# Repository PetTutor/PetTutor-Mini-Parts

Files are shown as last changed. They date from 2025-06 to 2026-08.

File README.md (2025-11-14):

# Pet Tutor Mini: Open-Source Wireless Dog Feeder for Training





## Project Overview

**Pet Tutor Mini** is an open-source, wireless dog feeder designed specifically for **positive reinforcement training**. It dispenses small treats remotely via a mobile app or web interface, helping trainers reward behaviors instantly without interrupting sessions. Built with affordable 3D-printed parts and off-the-shelf electronics, it's customizable, hackable, and perfect for dog owners, trainers, or hobbyists. The original Pet Tutor was created by Smart Animal Training Systems, LLC in 2012 and has gone  through several generations with the new one being the Pet Tutor Mini which is the subject of this open-source project. The Pet Tutor Mini is sold as a completed unit; ;however for hobbiests and developers the parts are provided here at no charge. The Pet Tutor is available for wheelchairs with interfaces for accessibility.

### Key Features
- **Wireless Control**: Bluetooth(50 feet) or Wi-Fi connectivity(internet via MQTT broker) for remote treat dispensing.
- **Modular Design**: Easy-to-print parts.
- **USB-C power plug for Wall or external battery**: A standard USB-C cable and wall plug or external USB style battery provide power.
- **Smart Features**: Auto dispense from browser or app.
- **Open-Source Everything**: Full schematics, code(c++), and files shared under CC BY-SA 4.0 (attribution required; share-alike for derivatives).

> **Note**: While the designs are free to build and modify, commercial versions sold by Smart Animal Training Systems,LLC under the "Pet Tutor" brand include premium support, custom firmware, and quality-tested components—check [Pet Tutor store](https://pettutor.biz) for those.

<!-- remove
# 🐾 PetTutor Mini Parts

Welcome to the **PetTutor Mini Parts** repository! This repo contains 3D printable files, diagrams, and documentation for parts of the **PetTutor Mini** that are available for public use, repair, or customization.

## 📦 What's Included
-->

## This Pet Tutor Mini repository currently includes:

- ✅ STL files for printable components (non-proprietary)
- ✅ Exploded diagrams showing part relationships
- ✅ Licensing information for personal and educational use

> ⚠️ Note: This repository does **not** include any proprietary or internal mechanisms protected under patent or intellectual property rights. Please see the [LICENSE](https://github.com/PetTutor/PetTutor-Mini-Parts/blob/main/LICENSE) section for more info.
<!-- comment out
## 🧩 Available Parts

| Module Name | File Type | Print Notes | Status |
|---|---|---|---|
| [Canister](https://github.com/PetTutor/PetTutor-Mini-Parts/blob/main/Canister/Readme.md) | `.stl` | PLA 0.2mm layer | Public |
| [Tumbler](https://github.com/PetTutor/PetTutor-Mini-Parts/blob/main/Tumbler/Readme.md) | `.stl` | Most PLA 0.2mm layer | Public |
| [PowerBase ESP32](https://github.com/PetTutor/PetTutor-Mini-Parts/blob/main/PowerBase%20ESP32/README.md) | `.stl` | PLA 0.2mm layer | Public |
| [PowerBase Atom](https://github.com/PetTutor/PetTutor-Mini-Parts/tree/main/PowerBase%20Atom/README.md) | `.stl` | PLA 0.2mm layer | Public |
| [Clickers](https://github.com/PetTutor/PetTutor-Mini-Parts/tree/main/Clickers) | `.stl` | PLA 0.2mm layer | Public |

-->
> Need a specific part? Open an issue or submit a request!
> 
# Modules Available   

| Module Name | Description | Contains sw/3D/electronics |
|---|---|:---:|
| [Canister][ca] | Container for food. 1 cup is standard but larger versions are included | 3D |
| [Dispense Mechanism][dm] | This part moves the kibble out of the feeder. It fits into the canister module. The brushes can be printed(TPU) or purchased | 3D |
| [PetTutor Software][sw] | The software is for the PowerBase, Remotes and mobile apps | sw |
| [PowerBase Atom][pba] | The PowerBase contains the stepper motor, Atom and 3D parts | 3D/Elec |
| [PowerBase ESP32][pbe] | Inactive version. No longer in use but provided for information | 3D/Elec |
| [Remotes][rm] | There are two versions of the remote: advanced and basic. The advanced has a larger button for accessibility  | 3D/Elec |

## 🤝 Contributions

We welcome:

- Suggestions for improvements
- Bug reports for fit or functionality
- Requests for additional public-facing parts

Please submit a pull request or open an issue if you’d like to contribute!
## Other resources and contributors to the open Pet Tutor community  
- **[Kona Currents](https://github.com/konacurrents/konacurrents)** :Inventor of the Semantic Marker(r) and developer of advanced firmware for the Pet Tutor

## 📄 License

All parts in this repository are provided under the **Creative Commons Attribution-NonCommercial-ShareAlike 4.0 International (CC BY-NC-SA 4.0)** license.

You are free to:

- Share and adapt the files
- Remix or build upon them

Under the following terms:

- 🏷️ **Attribution** – Give appropriate credit
- 💸 **NonCommercial** – Not for commercial use
- 🔄 **ShareAlike** – Distribute derivatives under the same license

Full license text available [here](https://creativecommons.org/publicdomain/zero/1.0/deed.en).

## 🖨️ 3D Printing Help

If you want to print your own parts and are new to 3D printing follow these simple steps:

STL Files: Download all printable parts from the /stl folder.

Find a friend or local library with 3D printer and ask them to aid in printing.

Recommended Settings:

Layer Height: 0.2 mm

Infill: 15%

Supports: Non unless specified

Other Print Settings: Default

Material: PLA unless otherwise specified

Assembly Tips:

Test-fit parts before gluing or screwing.

Clean up small holes with a drill bit if too tight.

Refer to the exploded diagrams for part orientation.

Need help? Open an issue or start a discussion on this repo.

## 📬 Contact & Support

For technical support or feedback, please contact:

📧 **PetTutor@SmartAnimalTraining.com** 

🌐 [www.pettutor.biz](https://smartanimaltraining.com/)  <-Assembled and tested units available here.

---

Thank you for supporting innovation, repairability, and pet care!

🐶🐱 – *The PetTutor Team*

[ca]: https://github.com/PetTutor/PetTutor-Mini-Parts/tree/main/Canister  
[dm]: https://github.com/PetTutor/PetTutor-Mini-Parts/tree/main/Dispense%20Mechanism
[sw]: https://github.com/PetTutor/PetTutor-Mini-Parts/tree/main/PetTutor%20Software  
[pba]: https://github.com/PetTutor/PetTutor-Mini-Parts/tree/main/PowerBase%20Atom
[pbe]: https://github.com/PetTutor/PetTutor-Mini-Parts/tree/main/PowerBase%20ESP32
[rm]: https://github.com/PetTutor/PetTutor-Mini-Parts/tree/main/Remotes

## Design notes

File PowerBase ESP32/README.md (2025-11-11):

# Older obsolete version of the Pet Tutor PowerBase  
*This version of the PowerBase is no longer made and uses a proprietary electronics board that is no longer made. This obsolete version used an EDP32 single board
processor and a custom interface board.
This is provided for information only.* 

**Click on a part to download:**

- [Base Top](https://github.com/PetTutor/PetTutor-Mini-Parts/blob/main/PowerBase%20ESP32/Base%20top.stl)
- [Center Ring](https://github.com/PetTutor/PetTutor-Mini-Parts/blob/main/PowerBase%20ESP32/Centering%20ring.stl)
- [28BYJ Motor Pin](https://github.com/PetTutor/PetTutor-Mini-Parts/blob/main/PowerBase%20ESP32/28BY-J%20Motor%20Pin.stl)
- [Base V2](https://github.com/PetTutor/PetTutor-Mini-Parts/blob/main/PowerBase%20ESP32/Base%20V2.stl)

All stl files are printed in PLA at .2 Layer Height and 15% infill.

Custom board is purchased through Pettutor.

Other items can be purchased through Amazon.

- [28By-J Motor](https://www.amazon.com/HiLetgo-ULN2003-28BYJ-48-Stepper-4-phase/dp/B00LPK0E5A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)
- [ESP 32](https://www.amazon.com/ESP-WROOM-32-Development-Microcontroller-Integrated-Compatible/dp/B08D5ZD528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)



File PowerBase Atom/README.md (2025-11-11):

- [PowerBase Atom Stepper Motor](https://github.com/PetTutor/PetTutor-Mini-Parts/tree/main/PowerBase%20Atom/PowerBase%20Atom%20Stepper)  This is the current version
- [PowerBase Atom DC Motor](https://github.com/PetTutor/PetTutor-Mini-Parts/tree/main/PowerBase%20Atom/PowerBase%20Atom%20DC%20Motor)

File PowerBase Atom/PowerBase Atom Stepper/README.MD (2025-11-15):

## Assemblies required for a complete Pet Tutor Mini are:  
1. Assembly Power Base Assembly (see parts list below)
2. Subassembly [Canister][ca] This container holds the food and screws onto the Dispense Mechanism to make the Food Assembly.
3. Subassembly [Dispense Mechanism][dm] This is the dispenser mechanism which separates out the kibble and drops it out of the feeder

---  

Base V5 Atom Exploded Assembly
Base V5 Atom Exploded Assembly (2)  

---  

## Bill of Materials Pet Tutor Mini PowerBase Assembly (*est costs in 2025)

| Item # | Part Name/link | Quantity | buy/3D print  | Description / Specs | Source / Supplier | Unit Cost* | Total Cost* |
|:---:|:---|:---:|:---:|:---|:---|---:|---:|
| 1 | [ATOM Lite ESP32 IoT Development Kit][Atom] | 1  | buy  | ATOM ESP32 | M5Stack | $7.50 | $7.50 |
| 2 | [ULN2003 Stepper Motor + ULN2003 Driver Board][db] | 1  | buy  | ELEGOO 28BYJ-48 ULN2003 5V Stepper Motor + ULN2003 Driver Board(5sets $15) | ELEGOO(Amazon) | $3.00 | $3.00 |
| 3 | [Buzzer][buz] | 1  | buy  | Buzzer with wires DC3-12v Active NOTE: must add 2 pin Dupont see [Build Instructions](#Build-Instructions) | bnafes(Amazon) | $0.58 | $0.58 |
| 4 | [Motor mount screws][mms] | 2  | buy  | Phillips Rounded Head Thread-Forming Screws(box 50 $16.46) | McMaster-Carr | $0.33 | $0.66 |
| 5 | [Shoulder screws][scr] | 2  | buy  | Mod-eez 2155 Shoulder Screw 5 mm x 5/8″ (pkg 25 $8.99) | Knapp | $0.36 | $0.72 |
| 6 | [4 pin cable&connectors female 10 cm][4p] | 1  | buy  | Dupont 2.54mm Wire Female to Female Connector & 22AWG Pre-Crimped Cable (motor driver), Single Row 10cm (5pkg $8) | Amazon | $1.60 | $1.60 |
| 7 | [2 pin cable&connectors 30 cm][2p] | 1  | buy  | Dupont 2.54mm Wire Female to Female Connector & 22AWG Pre-Crimped Cable, (motor driver&buzzer) (5 pkg $7.64) | Amazon | $1.53 | $1.53 |
| 8 | [BaseV5 Stepper - 1.stl][s1] | 1  | 3D | Main base for electronics  PLA any color | PLA color choice | n/a | n/a |
| 9 | [BaseV5 Stepper - 2 Clear.stl][cs] | 1  | 3D | Channel for LED light on ATOM clear filament required | ex. [Coex Natural PLA][cn]  | n/a | n/a |
| 10 | [BaseV5 Stepper - 3.stl][s3] | 1  | 3D | Holder for ATOM PLA | PLA color choice | n/a | n/a |
| 11 | [Base top Stepper.stl][ts] | 1  | 3D | Clear top holds motor and transmits led light PLA | ex. [Coex Natural PLA][cn]  | n/a | n/a |
| 12 | [28BY-J Motor Pin.stl][mp] | 1  | 3D | Motor pin fits over motor shaft and drive dispenser | PLA color choice | n/a | n/a |
| 13 | [Centering ring Stepper.stl][crs] | 1  | 3D | Centering ring aligns dispenser | PLA color choice | n/a | n/a |
---

## Build Instructions:  
- All 3D stl files are printed in PLA at .2 Layer Height and 15% infill.
- Cables connect ATOM to stepper motor driver board(2 pin & 4 pin).
- *Add buzzer connector*: 2 wires from buzzer require adding Dupont 2-pin connector. [Kit with tool and connector][tool]
- The motor pin is glued(ex. silicon glue) on the motor shaft. Note: height is critical along the shaft so mount motor and use the dispense canister assembly to push the pin down on shaft with glue
- Advanced firmware option: This has capabilites to allow the Pet Tutor Mini to connect to both WiFi and Bluetooth. It also can run other addons via the Groove connector.
- In addition to the feeder electronics module the dispenser is required and attached to the module. The food assembly is built from: [Canister][ca] and [Dispense Mechanism][dm] The Dispense Mechanism subassembly fits inside the Canister subassembly and this food assembly twists onto the PowerBase assembly.
- Basic firmware option:  This allows the feeder to be controlled from bluetooth.

---

*Last updated: November 14, 2025*

<!-- The links below will not show up in the render but are used as shortcuts in the code -->
[Atom]: https://shop.m5stack.com/products/atom-lite-esp32-development-kit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
[buz]: https://www.amazon.com/QMseller-Connector-Active-Plastic-Electronic/dp/B07VX87W5Q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
[scr]: https://knappconnectors.com/mod-eez-system/shoulder-screws/mod-eez-2155-shoulder-screw-5mm-x-5-8-inch/
[4p]: https://www.amazon.com/gp/aw/d/B0CCV3NJ8Q/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
[2p]: https://www.amazon.com/gp/aw/d/B0CCV3PXFP/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
[s1]: https://github.com/PetTutor/PetTutor-Mini-Parts/blob/main/PowerBase%20Atom/PowerBase%20Atom%20Stepper/BaseV5%20Stepper%20-%201.stl
[db]: https://www.amazon.com/ELEGOO-28BYJ-48-ULN2003-Stepper-Arduino/dp/B01CP18J4A
[mms]: https://www.mcmaster.com/catalog/131/3432/99461A505
[cs]: https://github.com/PetTutor/PetTutor-Mini-Parts/blob/main/PowerBase%20Atom/PowerBase%20Atom%20Stepper/BaseV5%20Stepper%20-%202%20Clear.stl
[s3]: https://github.com/PetTutor/PetTutor-Mini-Parts/blob/main/PowerBase%20Atom/PowerBase%20Atom%20Stepper/BaseV5%20Stepper%20-%203.stl
[ts]: https://github.com/PetTutor/PetTutor-Mini-Parts/blob/main/PowerBase%20Atom/PowerBase%20Atom%20Stepper/Base%20top%20Stepper.stl
[mp]: https://github.com/PetTutor/PetTutor-Mini-Parts/blob/main/PowerBase%20Atom/PowerBase%20Atom%20Stepper/28BY-J%20Motor%20Pin.stl
[crs]: https://github.com/PetTutor/PetTutor-Mini-Parts/blob/main/PowerBase%20Atom/PowerBase%20Atom%20Stepper/Centering%20ring%20Stepper.stl
[dm]: https://github.com/PetTutor/PetTutor-Mini-Parts/tree/main/Dispense%20Mechanism
[cn]: https://coex3d.com/products/natural-pla-175mm-1kg
[tool]: https://www.amazon.com/Taiss-Ratcheting-Connector-Crimping-Terminal/dp/B0B11RLGDZ?th=1
[ca]: https://github.com/PetTutor/PetTutor-Mini-Parts/tree/main/Canister

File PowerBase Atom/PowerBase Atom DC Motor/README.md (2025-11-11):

# Two versions of the PowerBase: Stepper motor(recommended) and DC Motor(not recommended)

During development a version of the PowerBase using a *DC motor* was developed and tested. That is the version listed below.  However, during testing
we found the noise from motor scared some dogs. While this version had superior torque the noise was too great. So the new version using the *stepper motor* was decveloped and is now in production. This is provided for anyone that would like to experiement with a different version.

**Click on a part to download:**

- [Base Top v5](https://github.com/PetTutor/PetTutor-Mini-Parts/blob/main/PowerBase%20Atom/Base%20top%20V5.stl)
- [BaseV5 - 1](https://github.com/PetTutor/PetTutor-Mini-Parts/blob/main/PowerBase%20Atom/BaseV5%20-%201.stl)
- [BaseV5 - 2](https://github.com/PetTutor/PetTutor-Mini-Parts/blob/main/PowerBase%20Atom/BaseV5%20-%202%20Clear.stl)
- [BaseV5 - 3](https://github.com/PetTutor/PetTutor-Mini-Parts/blob/main/PowerBase%20Atom/BaseV5%20-%203.stl)
- [Centering Ring V5](https://github.com/PetTutor/PetTutor-Mini-Parts/blob/main/PowerBase%20Atom/Centering%20ring%20V5.stl)
- [N20 Motor Pin](https://github.com/PetTutor/PetTutor-Mini-Parts/blob/main/PowerBase%20Atom/N20%20Motor%20Pin.stl)

All stl files are printed in PLA at .2 Layer Height and 15% infill. 

Other items can be purchased through Amazon or other vendors.

- [Atom](https://shop.m5stack.com/products/atom-lite-esp32-development-kit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)
- [N20 Motor](https://www.amazon.com/DIANN-10pcs-Micro-Motor-Gearbox/dp/B0CRKXXGXC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)
- [L9110 Motor Driver](https://www.amazon.com/HiLetgo-H-bridge-Stepper-Controller-Arduino/dp/B00M0F243E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)
- [Buzzer](https://www.amazon.com/QMseller-Connector-Active-Plastic-Electronic/dp/B07VX87W5Q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)




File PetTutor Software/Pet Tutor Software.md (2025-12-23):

# Software packages for Pet Tutor  
- **Feeder:** The firmware in the feeder allows it to wirelessly connect to BLE(Bluetooth Low Energy) devices like a phone or one of the Pet Tutor remotes. The feeder can also simultaneously connect to WiFi to provide control over the internet from a browser. The internet option uses a MQTT IOT broker to manage status and control to the feeder.
- **Remote:** This firmware allows the remote to find and connect to the feeder using BLE. The button on the remote sends the feed command to the feeder over BLE.
- **Phones:** The apps for Android and iOS provide the phone with the ability to connect to the feeder via BLE and send commands.  In addition the user can use a browser on the phone to send feed commands over the internet from the phone. Using the phone browser does NOT require an app and just uses the browser.
- **Summary:** The feeder can be controlled via BLE or WiFI or both at the same time. The remotes or phones can be used for BLE connection which is easy to setup but has shorter range. For longer range the WiFi option is a good choice. When using WiFi the feeder is setup with credentials for the local WiFi router(SSID/Password) and user cloud account(ID/Password). Customers who buy the Pet Tutor Mini will get a free cloud account but DIY builders will need to provide their own cloud MQTT broker. Basic functions firmware for the feeder and remote can be downloaded and compiled on the Arduino IDE.

---  
# Firmware for devices and apps for the phone  

| Device | Software download link | binary/source | Description | Software Contributor  | Comment |
|:---:|:---|:---:|:---:|:---:|:---|
| Android | [Android APK][apk] | binary| Not in app store. download and manually install  | Pet Tutor (Orion Patrie) | | 
| iOS | [Apple iOS][ios] | binary| In Apple Store for fee | Kona Currents,LLC (Scott Moody) | Several advanced features to monitor MQTT traffic, Semantic Marker developer |  
| Feeder | [Arduino ino][ino] | source | Arduino source code (c++) | Pet Tutor (Orion Patrie) | Basic firmware |  
| Feeder | [Advanced firmware][kc] | source | Arduino source code (c++) | [Kona Currents,LLC (Scott Moody)][kc] | Advanced firmware |  
| Basic Remote  | [Basic Remote][frmRemote]  | source | Basic remote Arduino C++  | Pet Tutor (Orion Patrie)  | |  

---

*Updated 11 NOV 2025*

---
[apk]: https://drive.google.com/file/d/19x49JGUla84gN7AuETKdELnhjsQVB5Vx/view?usp=sharing
[frm]: https://github.com/PetTutor/PetTutor-Mini-Parts/blob/main/PetTutor%20Basic%20Software/PTMini_Basic.ino
[ios]: https://apps.apple.com/us/app/semanticmarker/id6443887496  
[ino]: https://github.com/PetTutor/PetTutor-Mini-Parts/blob/main/PetTutor%20Software/PTMini_Basic.ino
[kc]: https://github.com/konacurrents/konacurrents
[frmRemote]: https://github.com/PetTutor/PetTutor-Mini-Parts/blob/main/PetTutor%20Software/PTClicker.ino

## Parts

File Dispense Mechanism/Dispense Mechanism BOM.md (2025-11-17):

# Exploded view of Dispense Mechanism (with PowerBase Assembly)  

BTum Parts

---

## Bill of Materials: Dispense Mechanism

| Item # | Part Name/link | Quantity | buy/3D print  | Description / Specs | Source / Supplier | Unit Cost* | Total Cost* |
|:---:|:---|:---:|:---:|:---|:---|---:|---:|
| 1 | [BTum - 1][bt1] | 1  | 3D | BTum 1.STL (PLA) | PLA color choice | na | na |
| 2 | [BTum - 2][bt2] | 1  | 3D | BTum 2.STL (PLA) | PLA color choice | na | na |
| 3 | [BTum - 3][bt3] | 1  | 3D | BTum 3.STL (PLA) | PLA color choice | na | na |
| 4 | [BTum - 4][bt4] | 1  | 3D | BTum 4.STL (TPU) | PLA color choice | na | na |
| 5 | [BTum - ST Adapter][bta] | 1  | 3D | BTum - ST Adapter.STL (PLA) optional Small Treat Adapter | PLA color choice | na | na |
| 6 | Brush waffer | 10 | 3D/buy  | 10 brush wafers can be printed in TPU [BTum 5.STL][bt5] or buy silicone type with better long term performance | [TPU][bta] or [silicone][si] | $4.00 silicone | $40.00 [silicone set][si] |

---

## Build Instructions:  
- All 3D stl files are printed in PLA at .2 Layer Height and 15% infill
- BTum 4 is printed out of TPU at .2 layer height and 15% infill
- Silicon brushes are not printed and need to be purchased from PetTutor or you can download and print BTum - 5 out of TPU.  The TPU version do not last as long as the silicon brushes and will need to be changed often.
---

*Last updated: November 10, 2025*  

[bt1]: https://github.com/PetTutor/PetTutor-Mini-Parts/blob/main/Dispense%20Mechanism/BTum%20%20-%201.stl  
[bt2]: https://github.com/PetTutor/PetTutor-Mini-Parts/blob/main/Dispense%20Mechanism/BTum%20-%202.stl
[bt3]: https://github.com/PetTutor/PetTutor-Mini-Parts/blob/main/Dispense%20Mechanism/BTum%20-%203.stl
[bt4]: https://github.com/PetTutor/PetTutor-Mini-Parts/blob/main/Dispense%20Mechanism/BTum%20-%204%20TPU.stl  
[bt5]: https://github.com/PetTutor/PetTutor-Mini-Parts/blob/main/Dispense%20Mechanism/BTum%20-%205%20TPU.stl  
[bta]: https://github.com/PetTutor/PetTutor-Mini-Parts/blob/main/Dispense%20Mechanism/BTum%20-%20ST%20Adapter.stl  
[si]: https://smartanimaltraining.com/products/brush-waffer-silicone-set

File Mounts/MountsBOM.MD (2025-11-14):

# The feeder has 2 holes in the bottom that allow it to attach to accessory mounts.  

## Mounts  
- Floor base bowl. This can be set on the floor or attached to a wheelchair mount  
- Wheelchair mounts

<!--  comment out
# Mounts  

| Item # | Part Name/link | Quantity | buy/3D print  | Description / Specs | Source / Supplier | Unit Cost* | Total Cost* |
|:---:|:---|:---:|:---:|:---|:---|---:|---:|
| 1 | [Floor mount.stl][fm] | 1  | 3D | 1 Cup Canister.stl (PLA) | PLA color choice | na | na |
| 2 | [1.5 Cup Canister.stl][c2] | 1  | 3D | 1.5 Cup Canister.stl (PLA) | PLA color choice | na | na |
| 3 | [2 Cup Canister.stl][c3] | 1  | 3D | 2 Cup Canister.stl (PLA) | PLA color choice | na | na |
| 4 | [Can x4 - 4 Cup Canister.stl][c4] | 1  | 3D | Can x4 - 4 Cup Canister.stl | PLA color choice | na | na |
| 5 | [Lid.stl][ld] | 1  | 3D | Lid (PLA) | PLA color choice | na | na |

comment out -->
---

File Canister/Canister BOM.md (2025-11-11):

# Canister Exploded View and BOM



---
# Canister BOM  

| Item # | Part Name/link | Quantity | buy/3D print  | Description / Specs | Source / Supplier | Unit Cost* | Total Cost* |
|:---:|:---|:---:|:---:|:---|:---|---:|---:|
| 1 | [1 Cup Canister.stl][c1] | 1  | 3D | 1 Cup Canister.stl (PLA) | PLA color choice | na | na |
| 2 | [1.5 Cup Canister.stl][c2] | 1  | 3D | 1.5 Cup Canister.stl (PLA) | PLA color choice | na | na |
| 3 | [2 Cup Canister.stl][c3] | 1  | 3D | 2 Cup Canister.stl (PLA) | PLA color choice | na | na |
| 4 | [Can x4 - 4 Cup Canister.stl][c4] | 1  | 3D | Can x4 - 4 Cup Canister.stl | PLA color choice | na | na |
| 5 | [Lid.stl][ld] | 1  | 3D | Lid (PLA) | PLA color choice | na | na |

---
All STL files should be properly aligned for support-free
printing. Note some slicers may complain about floating cantilevers on
the "cup" objects, however this can safely be ignored.

Suggested print settings include

* Matte or "Basic" PLA
* 0.4mm nozzle, with 0.2mm layer height
* 15% "grid" infill, 2 walls, 3 top / bottom layers

[c1]: https://github.com/PetTutor/PetTutor-Mini-Parts/blob/main/Canister/1%20%20Cup%20Canister.stl  
[c2]: https://github.com/PetTutor/PetTutor-Mini-Parts/blob/main/Canister/1.5%20Cup%20Canister.stl  
[c3]: https://github.com/PetTutor/PetTutor-Mini-Parts/blob/main/Canister/2%20Cup%20Canister.stl  
[c4]: https://github.com/PetTutor/PetTutor-Mini-Parts/blob/main/Canister/Can%20x4%20-%204%20Cup%20Canister.stl  
[ld]: https://github.com/PetTutor/PetTutor-Mini-Parts/blob/main/Canister/Lid.stl

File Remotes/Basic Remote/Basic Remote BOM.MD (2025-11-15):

## Pet Tutor Mini:  Basic Remote  
This remote provides a basic function of connecting to the feeder and provide a simple button to trigger the feeder.  

---
Clicker  

---

## Bill of Materials: Basic Remote

| Item # | Part Name/link | Quantity | buy/3D print  | Description / Specs | Source / Supplier | Unit Cost* | Total Cost* |
|:---:|:---|:---:|:---:|:---|:---|---:|---:|
| 1 | [ATOM Lite ESP32 IoT Development Kit][Atom] | 1  | buy | ATOM ESP32 | M5Stack | $7.50 | $7.50 |
| 2 | [ATOM Battery Accessory][tb] | 1  | buy | EATOM TailBat - Battery Accessory for ATOM is rechargeable | M5Stack | $9.50 | $9.50 |
| 3 | [Top Case.stl][tc] | 1  | 3D  | Top Case | PLA color choice | na | na |
| 4 | [Bottom Case.stl][bc] | 1  | 3D  | Bottom Case | PLA color choice | na | na |
| 5 | [Button.STL][bt] | 1  | 3D  | Button | PLA color choice | na | na |
| 6 | [Grip][gp] | 1  | 3D  |PTMini Clicker - Grip (TPU).stl | TPU | na | na |  

---  

## Build Instructions  

- All stl files are printed in PLA (Unless otherwise stated) at .2 Layer Height and 15% infill.

[Atom]: https://shop.m5stack.com/products/atom-lite-esp32-development-kit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  
[tb]: https://shop.m5stack.com/products/atom-tailbat  
[tc]: https://github.com/PetTutor/PetTutor-Mini-Parts/blob/main/Remotes/Basic%20Remote/PTMini%20Clicker%20-%20Top%20Case%20(PLA).stl  
[bc]: https://github.com/PetTutor/PetTutor-Mini-Parts/blob/main/Remotes/Basic%20Remote/PTMini%20Clicker%20-%20Bottom%20Case%20(PLA).stl  
[bt]: https://github.com/PetTutor/PetTutor-Mini-Parts/blob/main/Remotes/Basic%20Remote/PTMini%20Clicker%20-%20Button%20(Clear%20PLA).stl  
[gp]: https://github.com/PetTutor/PetTutor-Mini-Parts/blob/main/Remotes/Basic%20Remote/PTMini%20Clicker%20-%20Grip%20(TPU).stl

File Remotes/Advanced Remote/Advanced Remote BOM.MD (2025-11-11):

---  

## Pet Tutor Mini Advanced Remote  
This remote provides additions capabilities compared to the Basic Remote. Among other things the Advanced Remote has a big button which   
is useful for those with limited hand mobility. This unit also offers more options to attach other accessories.  

---
Smart Clicker (1)
---  

## Bill of Materials: Advanced Remote

| Item # | Part Name/link | Quantity | buy/3D print  | Description / Specs | Source / Supplier | Unit Cost* | Total Cost* |
|:---:|:---|:---:|:---:|:---|:---|---:|---:|
| 1 | [ATOM Lite ESP32 IoT Development Kit][Atom] | 1  | buy | ATOM ESP32 | M5Stack | $7.50 | $7.50 |
| 2 | [ATOM Battery Accessory][tb] | 1  | buy | EATOM TailBat - Battery Accessory for ATOM is rechargeable | M5Stack | $9.50 | $9.50 |
| 3 | [Button & cable][bt] | 1  | buy | Mechanical Key Button Unit includes HY2.0-4P Cable (20cm) | M5Stack | $3.95 | $3.95 |
| 4 | [Atom Extension][ae] | 1  | buy | ATOMIC PortABC Extension Base | M5Stack | $3.50 | $3.50 |
| 5 | [Handle Top.stl][ht] | 1  | 3D  | Top Handle | PLA color choice | na | na |
| 6 | [Handle Bottom.stl][hb] | 1  | 3D  | Handle Bottom | PLA color choice | na | na |

---

## Build Instructions:  
- All 3D stl files are printed in PLA at .2 Layer Height and 15% infill
- Firmware can be downloaded to operation the Advanced Remote and connect via Bluetooth Low Energy to the feeder.  

---

*Last updated: November 10, 2025*  

[Atom]: https://shop.m5stack.com/products/atom-lite-esp32-development-kit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  
[tb]: https://shop.m5stack.com/products/atom-tailbat  
[bt]: https://shop.m5stack.com/products/mechanical-key-button-unit 
[ae]: https://shop.m5stack.com/products/atomic-portabc-extension-base
[ht]: https://github.com/PetTutor/PetTutor-Mini-Parts/blob/main/Clickers/Smart%20Clicker/Handle%20Top.stl  
[hb]: https://github.com/PetTutor/PetTutor-Mini-Parts/blob/main/Clickers/Smart%20Clicker/Handle%20Bottom.stl

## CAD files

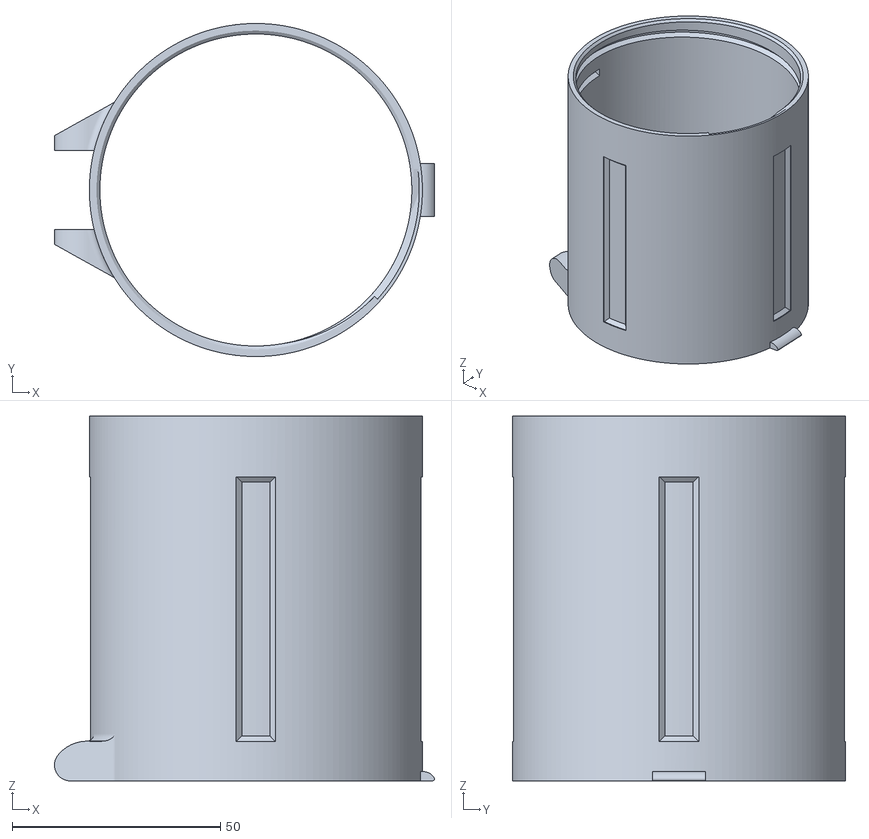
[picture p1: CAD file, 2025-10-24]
Canister/1 Cup Canister.stl
91.3 x 80.0 x 87.6

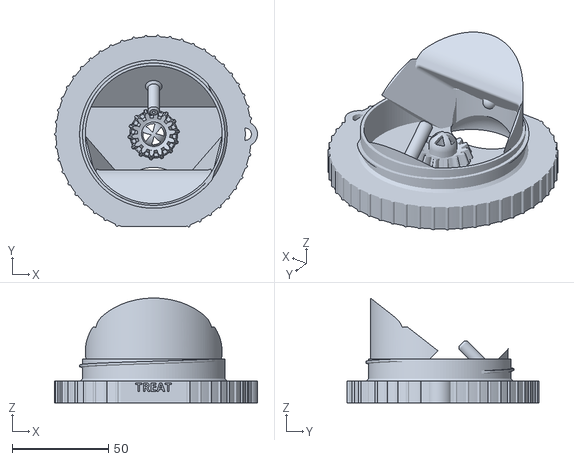
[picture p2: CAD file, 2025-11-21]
Dispense Mechanism/BTum - 1.stl
105.6 x 99.8 x 54.6

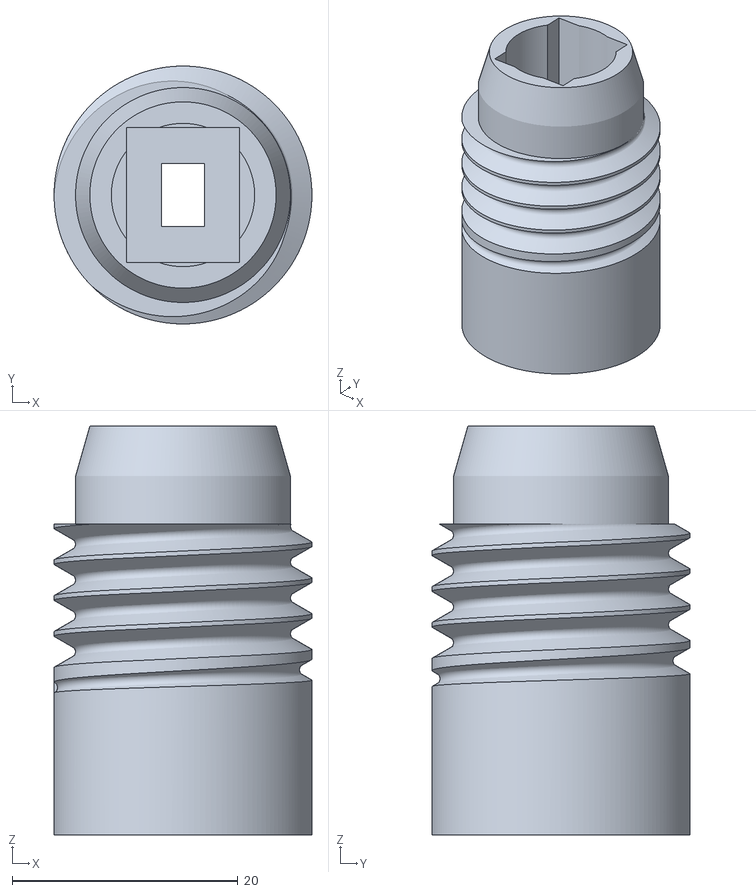
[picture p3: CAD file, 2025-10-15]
PowerBase Atom/PowerBase Atom DC Motor/Centering ring V5.stl
22.9 x 22.9 x 36.3

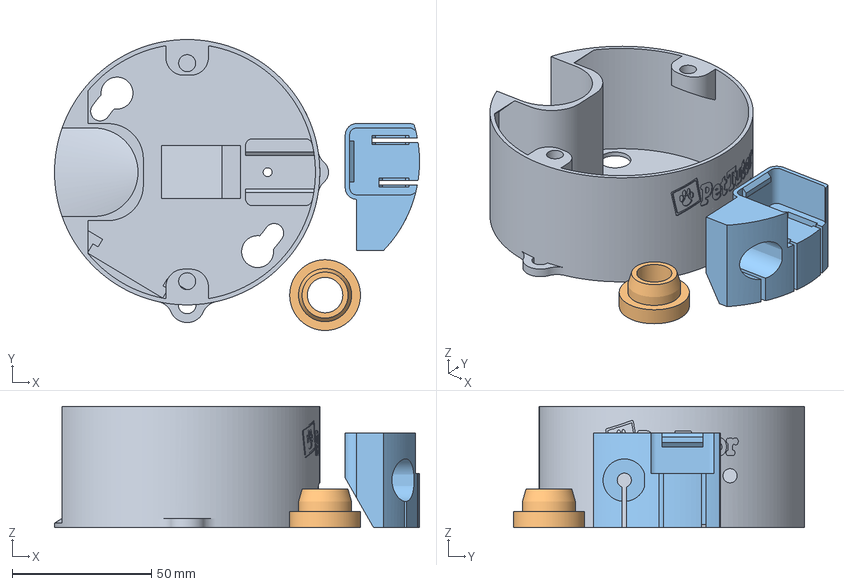
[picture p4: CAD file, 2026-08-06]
PowerBase Atom/PowerBase Atom Stepper/PowerBase Color Parts.3mf
131.0 x 104.4 x 43.5 mm
BaseV5 Stepper - 1.stl
Centering ring Stepper.stl
BaseV5 Stepper - 3.stl

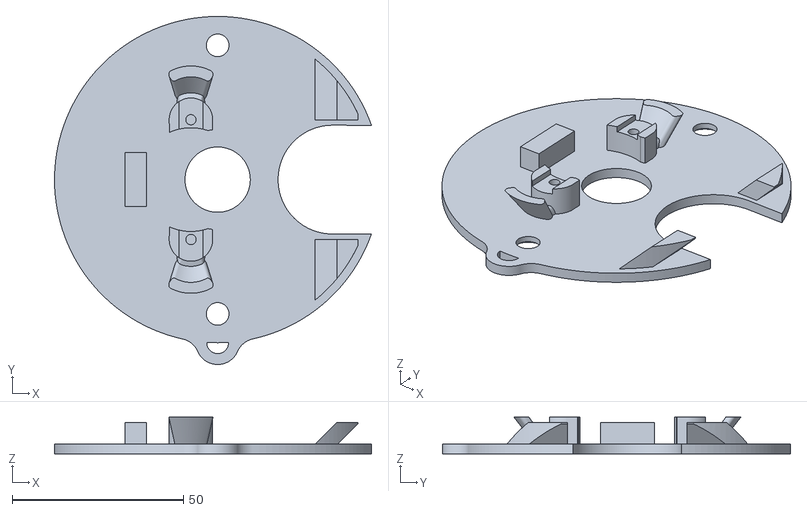
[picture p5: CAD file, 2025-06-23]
PowerBase ESP32/Base top.stl
92.5 x 101.6 x 10.8

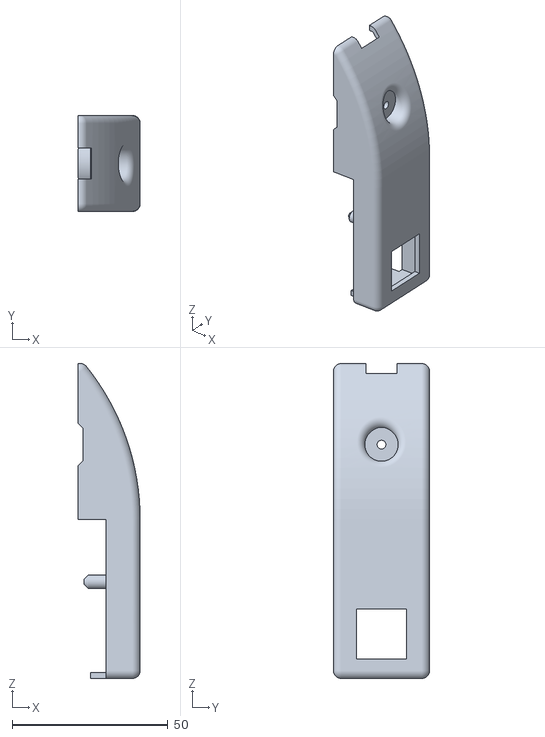
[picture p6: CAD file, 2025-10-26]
Remotes/Advanced Remote/Handle Bottom.stl
20.0 x 30.9 x 101.0

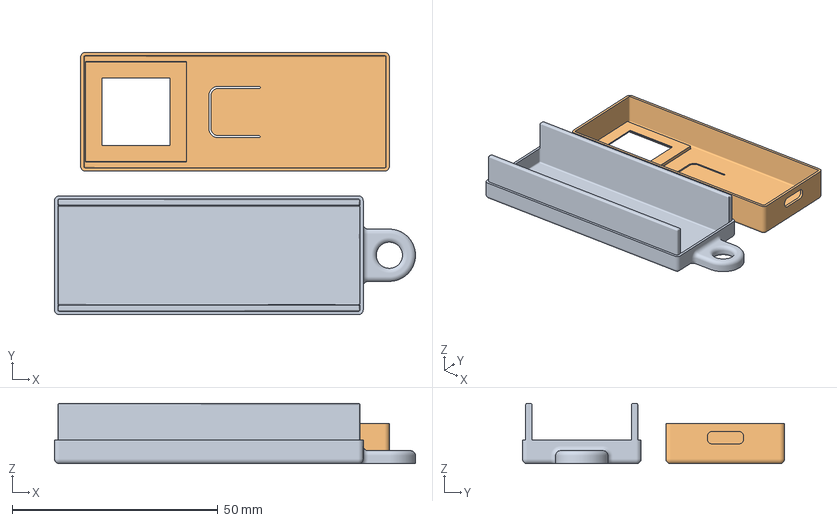
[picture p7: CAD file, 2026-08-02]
Remotes/Basic Remote/Remote Case.3mf
87.8 x 63.8 x 14.7 mm
Basic Remote - Bottom Case (PLA).stl
Basic Remote S3 - Top Case (PLA).stl

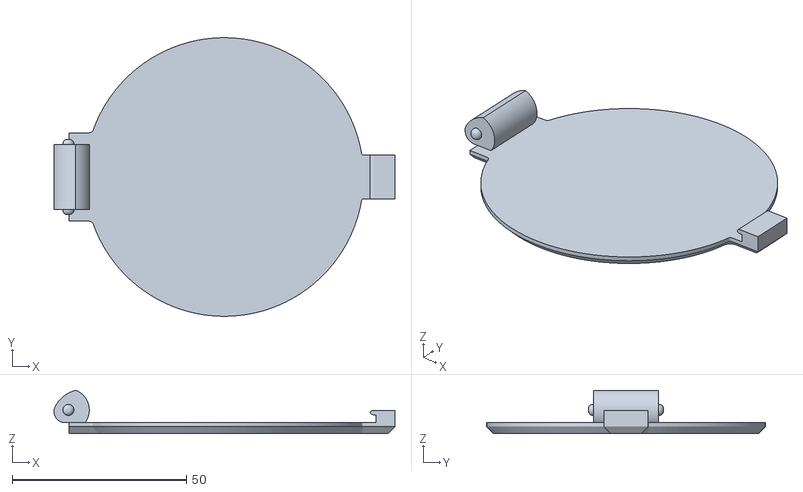
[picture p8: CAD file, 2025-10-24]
Canister/Lid.stl
97.9 x 80.0 x 12.5

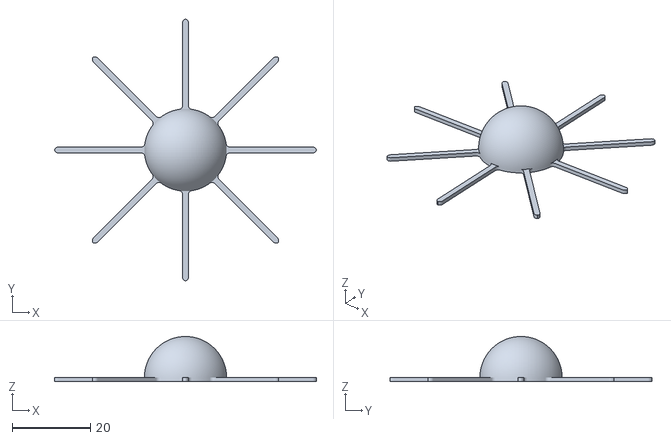
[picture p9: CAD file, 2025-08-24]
Dispense Mechanism/BTum - 4 TPU.stl
66.9 x 66.9 x 11.5

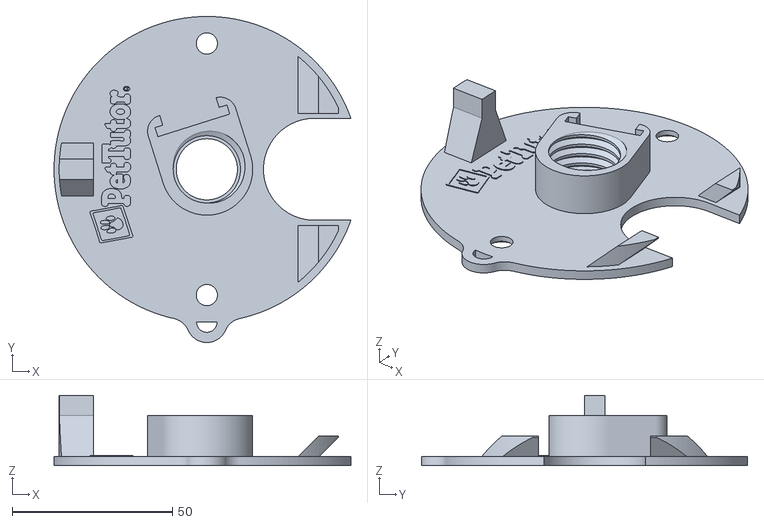
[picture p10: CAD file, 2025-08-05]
PowerBase Atom/PowerBase Atom DC Motor/Base top V5.stl
92.5 x 101.6 x 21.9

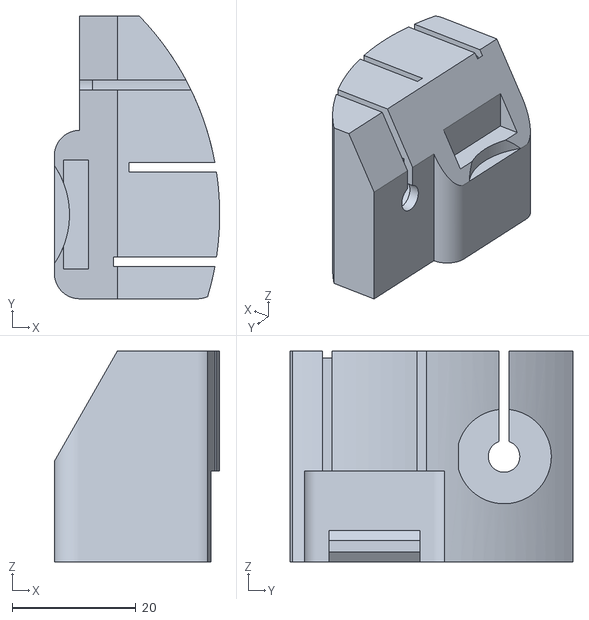
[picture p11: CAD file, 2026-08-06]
PowerBase Atom/PowerBase Atom Stepper/BaseV5 Stepper - 3.stl
26.7 x 45.6 x 34.0

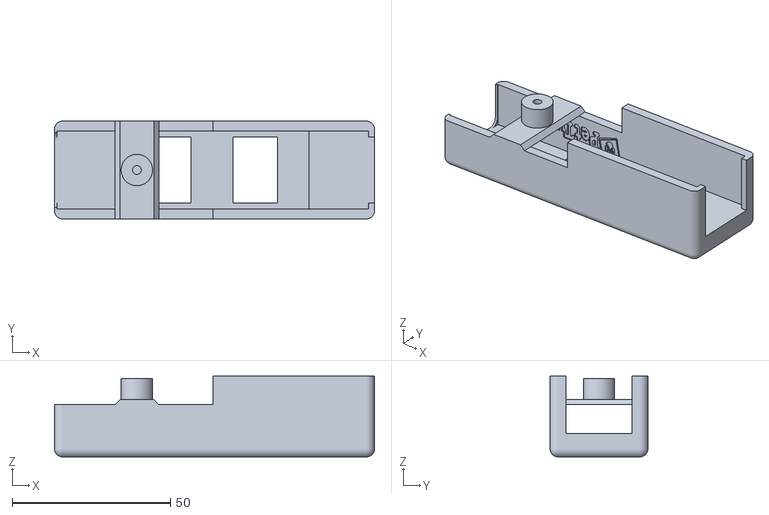
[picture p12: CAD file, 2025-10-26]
Remotes/Advanced Remote/Handle Top.stl
101.0 x 30.9 x 25.5

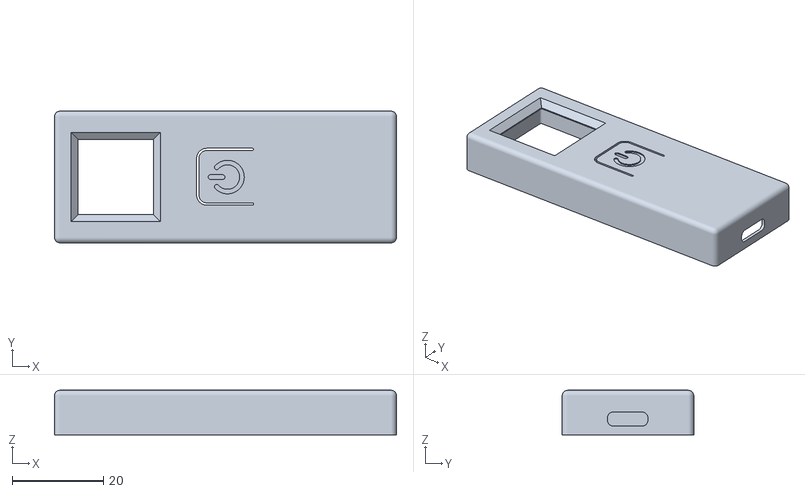
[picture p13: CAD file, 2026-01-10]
Remotes/Basic Remote/Basic Remote S3 - Top Case (PLA).stl
75.1 x 28.9 x 9.77

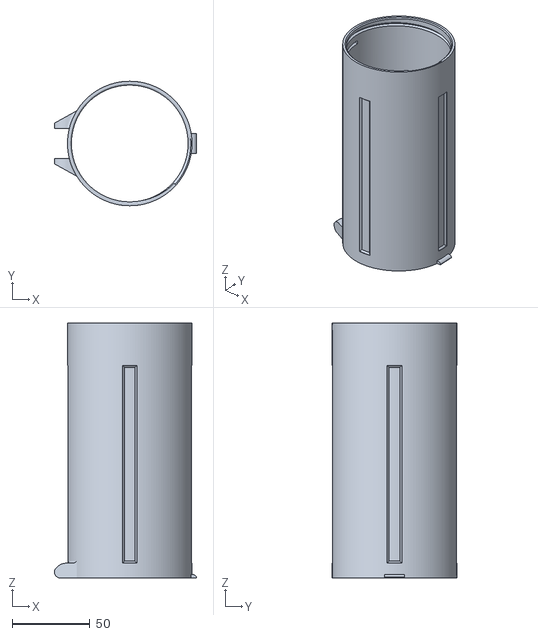
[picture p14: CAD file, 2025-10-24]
Canister/2 Cup Canister.stl
91.3 x 80.0 x 163.8

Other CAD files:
Dispense Mechanism/BTum - 3.stl
PowerBase Atom/PowerBase Atom DC Motor/BaseV5 - 3.stl
PowerBase Atom/PowerBase Atom Stepper/BaseV5 Stepper - 2 Clear.stl
Remotes/Basic Remote/Basic Remote - Top Case (PLA).stl
Canister/1.5 Cup Canister.stl
Canister/Can x4 - 4 Cup Canister.stl
Dispense Mechanism/BTum - 2.stl
Dispense Mechanism/BTum - 5 TPU.stl
Dispense Mechanism/BTum - ST Adapter.stl
PowerBase Atom/PowerBase Atom DC Motor/BaseV5 - 1.stl
PowerBase Atom/PowerBase Atom DC Motor/BaseV5 - 2 Clear.stl
PowerBase Atom/PowerBase Atom DC Motor/N20 Motor Pin.stl
PowerBase Atom/PowerBase Atom Stepper/28BY-J Motor Pin.stl
PowerBase Atom/PowerBase Atom Stepper/Base top Stepper.stl
PowerBase Atom/PowerBase Atom Stepper/BaseV5 Stepper - 1.stl
PowerBase Atom/PowerBase Atom Stepper/Centering ring Stepper.stl
Remotes/Basic Remote/Basic Remote - Bottom Case (PLA).stl
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

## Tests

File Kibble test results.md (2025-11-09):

# Results of testing kibble in Pet Tutor Mini

**Open in Google Docs (editable)** → [Kibble test results](https://docs.google.com/spreadsheets/d/1Jjmwx9EtroDBZK3UN8GiRwEKW_PLVF-9acC-SBAR-ZY/edit?gid=0#gid=0)

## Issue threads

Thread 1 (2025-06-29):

Wiring Diagram for M5Atom version

konacurrents, 2025-06-29:
The parts list and 3d printed parts are awesome.
Next people need to know is the wiring diagram for hooking up the motor and buzzer.

Here is one that Orion made in rough draft, but useful.

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

# M5 Atom Wiring
The diagram above corresponds to the following of the M5Atom.

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

# Bootstrap program for getting the M5Atom software

- [ ] use this bootstrap program
[M5Atom Bootstrap Program](https://github.com/konacurrents/ESP_M5_BOOTSTRAP/tree/main
)

opatrie, 2025-07-01:
README.md was updated with wiring diagram.

https://github.com/PetTutor/PetTutor-Mini-Parts/blob/main/PowerBase%20Atom/README.md

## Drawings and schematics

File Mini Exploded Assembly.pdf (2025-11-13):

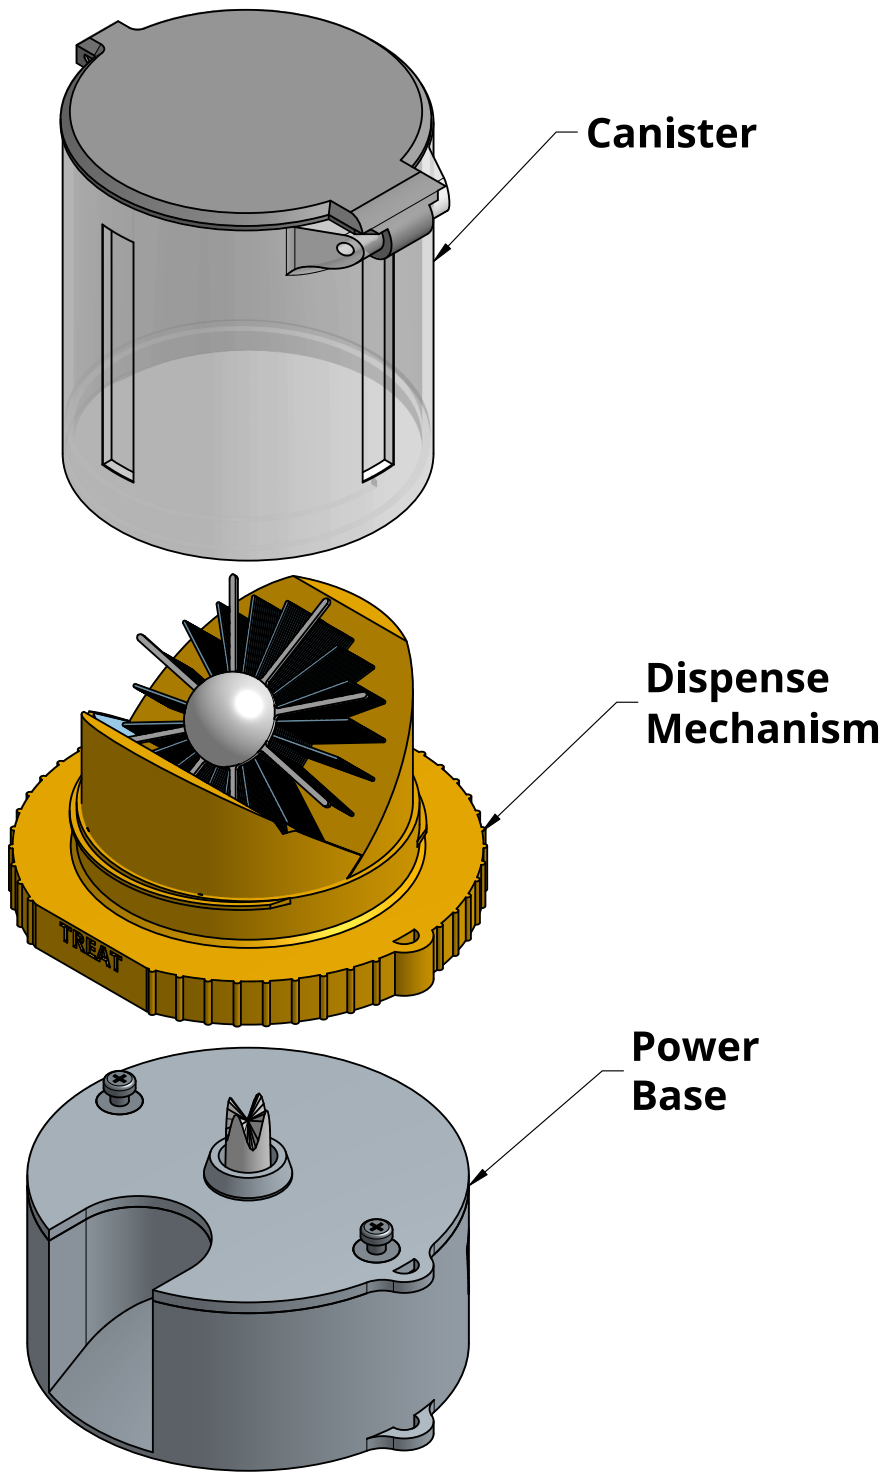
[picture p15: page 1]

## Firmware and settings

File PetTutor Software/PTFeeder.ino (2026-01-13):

#include <M5Atom.h>
#include <BLEDevice.h>
#include <BLEUtils.h>
#include <BLEServer.h>
#include <AccelStepper.h>

// ================= PINS =================
#define MOTOR_PIN1 22
#define MOTOR_PIN2 19
#define MOTOR_PIN3 23
#define MOTOR_PIN4 33

#define BUZZER1 21   // G21 HIGH
#define BUZZER2 25   // G25 LOW

// ================= STEPPER =================
AccelStepper stepper(AccelStepper::FULL4WIRE,
                     MOTOR_PIN1, MOTOR_PIN3,
                     MOTOR_PIN2, MOTOR_PIN4);

int stepsPerFeed = 200;
bool motorDirection = true;
bool motorRunning = false;
unsigned long motorStartTime = 0;

// ================= BUZZER =================
bool buzzerEnabled = false;   // controlled by B / b

// ================= BLE =================
#define SERVICE_UUID        "B0E6A4BF-CCCC-FFFF-330C-0000000000F0"
#define CHARACTERISTIC_UUID "B0E6A4BF-CCCC-FFFF-330C-0000000000F1"

BLEServer* pServer = nullptr;
BLECharacteristic* pCharacteristic = nullptr;

// ================= BLE CALLBACK =================
class MyCallbacks : public BLECharacteristicCallbacks {
  void onWrite(BLECharacteristic* characteristic) override {
    std::string value = characteristic->getValue();
    if (value.length() == 0) return;

    String rxValue = String(value.c_str());
    Serial.print("Received: ");
    Serial.println(rxValue);

    // ---- FEED ----
    if (rxValue == "s") {
      motorRunning = true;
      motorStartTime = millis();

      stepper.setMaxSpeed(600);
      stepper.setAcceleration(300);
      stepper.moveTo(motorDirection ? stepsPerFeed : -stepsPerFeed);
      motorDirection = !motorDirection;

      M5.dis.drawpix(0, 0xFF0000); // red during feed
    }

    // ---- BUZZER ENABLE ----
    else if (rxValue == "B") {
      buzzerEnabled = true;
      Serial.println("Buzzer enabled");
    }

    // ---- BUZZER DISABLE ----
    else if (rxValue == "b") {
      buzzerEnabled = false;
      digitalWrite(BUZZER1, LOW);
      digitalWrite(BUZZER2, LOW);
      Serial.println("Buzzer disabled");
    }

    // ---- CHANGE STEPS ----
    else {
      int newSteps = rxValue.toInt();
      if (newSteps > 0 && newSteps < 20000) {
        stepsPerFeed = newSteps;
        Serial.print("Steps per feed set to ");
        Serial.println(stepsPerFeed);
      }
    }
  }
};

void setup() {
  Serial.begin(115200);
  M5.begin(true, false, true);

  pinMode(BUZZER1, OUTPUT);
  pinMode(BUZZER2, OUTPUT);
  digitalWrite(BUZZER1, LOW);
  digitalWrite(BUZZER2, LOW);

  stepper.setMaxSpeed(600);
  stepper.setAcceleration(300);

  // BLE setup
  BLEDevice::init("PTFeeder");
  pServer = BLEDevice::createServer();
  BLEService* service = pServer->createService(SERVICE_UUID);

  pCharacteristic = service->createCharacteristic(
    CHARACTERISTIC_UUID,
    BLECharacteristic::PROPERTY_WRITE
  );

  pCharacteristic->setCallbacks(new MyCallbacks());
  service->start();

  BLEAdvertising* advertising = BLEDevice::getAdvertising();
  advertising->addServiceUUID(SERVICE_UUID);
  advertising->start();

  M5.dis.drawpix(0, 0xFFFFFF); // white = idle
  Serial.println("PTFeeder BLE ready");
}

void loop() {
  M5.update();

  // ---- MOTOR RUN ----
  if (motorRunning) {
    if (stepper.distanceToGo() != 0) {
      stepper.run();

      // ---- BUZZER DURING FEED ----
      if (buzzerEnabled && millis() - motorStartTime < 5000) {
        digitalWrite(BUZZER1, HIGH); // G21 HIGH
        digitalWrite(BUZZER2, LOW);  // G25 LOW
      } else {
        digitalWrite(BUZZER1, LOW);
        digitalWrite(BUZZER2, LOW);
      }
    } else {
      // Feed finished
      motorRunning = false;
      digitalWrite(BUZZER1, LOW);
      digitalWrite(BUZZER2, LOW);
      M5.dis.drawpix(0, 0x0000FF); // blue idle
    }
  }
}

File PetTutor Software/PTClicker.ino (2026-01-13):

#include <M5Atom.h>
#include <BLEDevice.h>
#include <BLEClient.h>
#include <BLEUtils.h>
#include "esp_sleep.h"

// UUIDs must match the feeder
#define SERVICE_UUID        "B0E6A4BF-CCCC-FFFF-330C-0000000000F0"
#define CHARACTERISTIC_UUID "B0E6A4BF-CCCC-FFFF-330C-0000000000F1"

// Atom button GPIO (Atom & Atom S3)
#define WAKE_BUTTON GPIO_NUM_39

// BLE objects
BLEClient* pClient;
BLERemoteCharacteristic* pRemoteCharacteristic;

// Button tracking
unsigned long pressStartTime = 0;
bool isPressed = false;
bool holdIndicated = false;

// States
bool buzzerState = false;

// Timing
unsigned long lastActivityTime = 0;
unsigned long lastReconnectAttempt = 0;

const unsigned long reconnectInterval = 5000;
const unsigned long SLEEP_AFTER_IDLE = 60000; // 1 minute

// ---------------- LED Helper ----------------
void setLED(uint32_t color) {
  M5.dis.drawpix(0, color);
}

// ---------------- Deep Sleep ----------------
void goToSleep() {
  Serial.println("Going to deep sleep...");
  setLED(0xFF8000); // orange
  delay(300);

  setLED(0x000000); // off
  esp_sleep_enable_ext0_wakeup(WAKE_BUTTON, 0); // wake on button LOW
  esp_deep_sleep_start();
}

// ---------------- Send Command ----------------
void sendCommand(const char* cmd) {
  if (pRemoteCharacteristic && pClient->isConnected()) {
    lastActivityTime = millis();
    setLED(0xFF0000); // red = sending
    pRemoteCharacteristic->writeValue((uint8_t*)cmd, strlen(cmd), true);
    delay(300);
    setLED(buzzerState ? 0x00FF00 : 0x0000FF);
  } else {
    setLED(0x800080); // purple = error
  }
}

// ---------------- Connect to Feeder ----------------
bool connectToFeeder() {
  setLED(0xFFFF00); // yellow = scanning

  BLEScan* pScan = BLEDevice::getScan();
  pScan->setActiveScan(true);
  BLEScanResults* results = pScan->start(5);

  for (int i = 0; i < results->getCount(); i++) {
    BLEAdvertisedDevice device = results->getDevice(i);
    if (device.haveServiceUUID() &&
        device.isAdvertisingService(BLEUUID(SERVICE_UUID))) {

      if (pClient->connect(&device)) {
        BLERemoteService* service =
          pClient->getService(BLEUUID(SERVICE_UUID));

        if (service) {
          pRemoteCharacteristic =
            service->getCharacteristic(BLEUUID(CHARACTERISTIC_UUID));

          if (pRemoteCharacteristic) {
            setLED(buzzerState ? 0x00FF00 : 0x0000FF);
            lastActivityTime = millis();
            pScan->clearResults();
            return true;
          }
        }
      }
    }
  }

  pScan->clearResults();
  return false;
}

// ---------------- Setup ----------------
void setup() {
  M5.begin(true, false, true);
  Serial.begin(115200);

  setLED(0xFFFFFF); // white = boot

  BLEDevice::init("");
  pClient = BLEDevice::createClient();

  lastActivityTime = millis();
  connectToFeeder();
}

// ---------------- Loop ----------------
void loop() {
  M5.update();

  // Auto-reconnect
  if (!pClient->isConnected()) {
    if (millis() - lastReconnectAttempt > reconnectInterval) {
      lastReconnectAttempt = millis();
      connectToFeeder();
    }

    if (millis() - lastActivityTime > SLEEP_AFTER_IDLE) {
      goToSleep();
    }

    delay(50);
    return;
  }

  // Button pressed
  if (M5.Btn.isPressed() && !isPressed) {
    pressStartTime = millis();
    isPressed = true;
    holdIndicated = false;
  }

  // While holding button → preview buzzer toggle result
  if (isPressed && !holdIndicated) {
    if (millis() - pressStartTime >= 2000) {
      if (buzzerState) {
        setLED(0x0000FF); // blue = buzzer will turn OFF
      } else {
        setLED(0x00FF00); // green = buzzer will turn ON
      }
      holdIndicated = true;
    }
  }

  // Button released
  if (M5.Btn.wasReleased()) {
    unsigned long pressDuration = millis() - pressStartTime;
    isPressed = false;
    lastActivityTime = millis();

    if (pressDuration >= 2000) {
      buzzerState = !buzzerState;
      sendCommand(buzzerState ? "B" : "b");
    } else {
      sendCommand("s");
    }

    // Final LED state
    setLED(buzzerState ? 0x00FF00 : 0x0000FF);
  }

  // Sleep after idle
  if (millis() - lastActivityTime > SLEEP_AFTER_IDLE) {
    goToSleep();
  }

  delay(50);
}

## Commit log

2025-06-24 Rename Readme.md to PowerBase ESP32 Exploded View.md
2025-06-24 Rename PowerBase ESP32 Exploded View.md to Readme.md
2025-06-25 Rename Tum 6.1 - 1 cup Canister.stl to 1 cup Canister.stl
    [1 cup Canister.stl]
2025-06-25 Rename Tum 6.1 - Lid.stl to Lid.stl
    [Lid.stl]
2025-06-25 Rename Tum 6x1.5 - 1.5 Cup Canister.stl to 1.5 Cup Canister.stl
    [1.5 Cup Canister.stl]
2025-06-25 Rename Tum 6x2 - 2 Cup Canister.stl to 2 Cup Canister.stl
    [2 Cup Canister.stl]
2025-07-06 Wrong lid and 1 Cup canister
    [1 Cup Canister.stl, Lid.stl]
2025-07-06 Deleted Logo
    [Lid.stl]
2025-07-11 TPU version of brushes
    [BTum - 5 TPU.stl]
2025-07-11 Made hole bigger to access grove connection.
    [BaseV5 - 1.stl]
2025-07-25 4 Cup canister
    [Can x4 - 4 Cup Canister.stl]
2025-08-05 opened up spot for pins 19 and 22
    [BaseV5 - 3.stl]
2025-08-05 Added mount for L9110S Driver Board
    Wire on motor were to short.
    [Base top V5.stl]
2025-08-24 Changed print orinatation
    [BTum - 2.stl]
2025-08-24 Changed print orientation
    [BTum - 3.stl, BTum - 4 TPU.stl]
2025-10-09 align canister parts against plate, include suggested printer settings
    [1 Cup Canister.stl, 1.5 Cup Canister.stl, 2 Cup Canister.stl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]
2025-10-10 flip base stepper part to align with base
    [BaseV5 Stepper - 1.stl]
2025-10-10 updated models to be aligned with plate axis
    [28BY-J Motor Pin.stl, BaseV5 Stepper - 1.stl, BaseV5 Stepper - 3.stl]
2025-10-15 Create PowerBase Atom DC Motor
2025-11-02 Made change to keep pins locked in place.
    [BaseV5 Stepper - 3.stl]
2025-11-07 Changed orientation
    [BaseV5 Stepper - 3.stl]
2025-11-09 Add REMOTE Bill of Materials and build instructions
    Added a detailed Bill of Materials and build instructions for the Mini Advanced Remote project.
2025-11-09 Document Pet Tutor Mini Feeder electronics module
    Added detailed assembly instructions and bill of materials for the Pet Tutor Mini Feeder electronics module, including links to parts and suppliers.
2025-11-09 Revise wiring instructions and add tool link
    Updated wiring instructions and added a link to the crimping tool.
2025-11-10 Update assembly and bill of materials references
2025-11-10 Rename Feeder Electronics module.MD to PowerBase Assembly.MD
2025-11-10 renamed folders for clickers
    [Handle Bottom.stl, Handle Top.stl, PTMini Clicker - Bottom Case (PLA).stl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]
2025-11-10 Enhance README with remote device details
    Added a brief explanation of the remotes and their purpose.
2025-11-10 Renamed folder from Tumbler to Dispense Mechanism
    [BTum - 1.stl, BTum - 2.stl, BTum - 3.stl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]
2025-11-10 Update assembly list terminology and links
2025-11-10 Update PowerBase Assembly.MD
2025-11-10 moved Advanced Remote BOM.MD to Remotes/Advanced Remote/Advanced Remote BOM.MD
2025-11-10 Update Advanced Remote BOM.MD
2025-11-10 move PowerBase Assembly.MD to PowerBase Atom/PowerBase Atom Stepper/PowerBase Assembly.MD
2025-11-10 Rename Basic Remote.MD to Basic Remote BOM.MD
2025-11-11 Rename Readme.md to Dispense Mechanism BOM.md
2025-11-11 Rename Readme.md to Canister BOM.md
2025-11-11 Update Canister BOM.md
2025-11-15 Update Basic Remote BOM.MD
2025-11-17 Update Dispense Mechanism BOM.md
2025-12-23 Basic remote with LED light status indicators
    Color
    Meaning
    ⚪ White
    Boot / wake
    🔵 Blue
    Idle, buzzer OFF (Hold button until it turns blue release and buzzer is off)
    🟢 Green
    Idle, buzzer ON (Hold button until it turns green release and buzzer is on)
    🔴 Red
    Sending command
    🟡 Yellow
    Scanning / reconnecting
    🟠 Orange
    Entering sleep
    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
    [PTClicker.ino]
2025-12-23 Rename PowerBase Assembly.MD to README.MD
2026-01-10 Rename PTMini Clicker - Button (Clear PLA).stl to Basic Remote - Button (Clear PLA).stl
    [Basic Remote - Button (Clear PLA).stl]
2026-07-30 Changes Made
    [BaseV5 Stepper - 1.stl, BaseV5 Stepper - 2 Clear.stl]

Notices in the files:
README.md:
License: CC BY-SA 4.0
